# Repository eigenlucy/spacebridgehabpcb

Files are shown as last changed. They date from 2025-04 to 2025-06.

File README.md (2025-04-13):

# SpaceBridge HAB PCB

High Altitude Balloon (HAB) PCB Tracker with cutdown mechanism, GPS, environmental monitoring, LoRa telemetry and particle detection capabilities.

Created by Lucy Moglia <eigenlucy@proton.me>

## Table of Contents
- [Overview](#overview)
- [Project Structure](#project-structure)
- [Block Diagram](#block-diagram)
- [Features](#features)
- [Getting Started](#getting-started)
  - [Building the Project](#building-the-project)
  - [Installation](#installation)
    - [Linux Installation](#linux-installation)
    - [Mac Installation](#mac-installation)
    - [Visual Studio Code/Cursor Extension](#visual-studio-codecursor-extension-install)

## Overview

The SpaceBridge HAB PCB is a comprehensive tracking and instrumentation system for high altitude balloon experiments. It integrates multiple subsystems including power management, telemetry, GPS tracking, environmental monitoring, and a particle counter based on CERN open source hardware.

## Project Structure

| Module | Source File | PCB Layout | Description |
|:---:|:---:|:---:|:---|
| Mainboard | [`mainboard.ato`](./mainboard.ato) | [`layouts/default/default.kicad_pcb`](./layouts/default/default.kicad_pcb) | Final PCB incorporating all submodules |
| MicroMPPT | [`micromppt/elec/src/micromppt.ato`](./micromppt/elec/src/micromppt.ato) | [`micromppt/elec/layout/default/micromppt.kicad_pcb`](./micromppt/elec/layout/default/micromppt.kicad_pcb) | 5W MPPT battery charger with embedded set point adjustment algorithm |
| Particle Counter | [`particle_counter.ato`](./particle_counter.ato) | [`layouts/particle-counter/particle-counter.kicad_pcb`](./layouts/particle-counter/particle-counter.kicad_pcb) | Alpha particle detector based on CERN open source hardware kit |
| Cutoff Mechanism | [`cutoff.ato`](./cutoff.ato) | [`layouts/cutoff/cutoff.kicad_pcb`](./layouts/cutoff/cutoff.kicad_pcb) | Balloon cutoff circuit using lithium hybrid supercapacitor discharging through nichrome wire |
| BQ24045DSQR BMS | [`bq24045dsqr/elec/src/bq24045dsqr.ato`](./bq24045dsqr/elec/src/bq24045dsqr.ato) | [`bq24045dsqr/elec/layout/default/bq24045dsqr.kicad_pcb`](./bq24045dsqr/elec/layout/default/bq24045dsqr.kicad_pcb) | 5V 1A single cell LiPo/Li-ion charger + BMS |
| TPS63020DSJR | `~/.ato/modules/tps63020dsjr/elec/src/tps63020dsjr.ato` | `~/.ato/modules/tps63020dsjr/elec/layout/tps63020dsjr.kicad_pcb` | 1.8V-5.5V In/Out 4A boost-buck converter (5V from Vbat) |

## Block Diagram

### Original Block Diagram
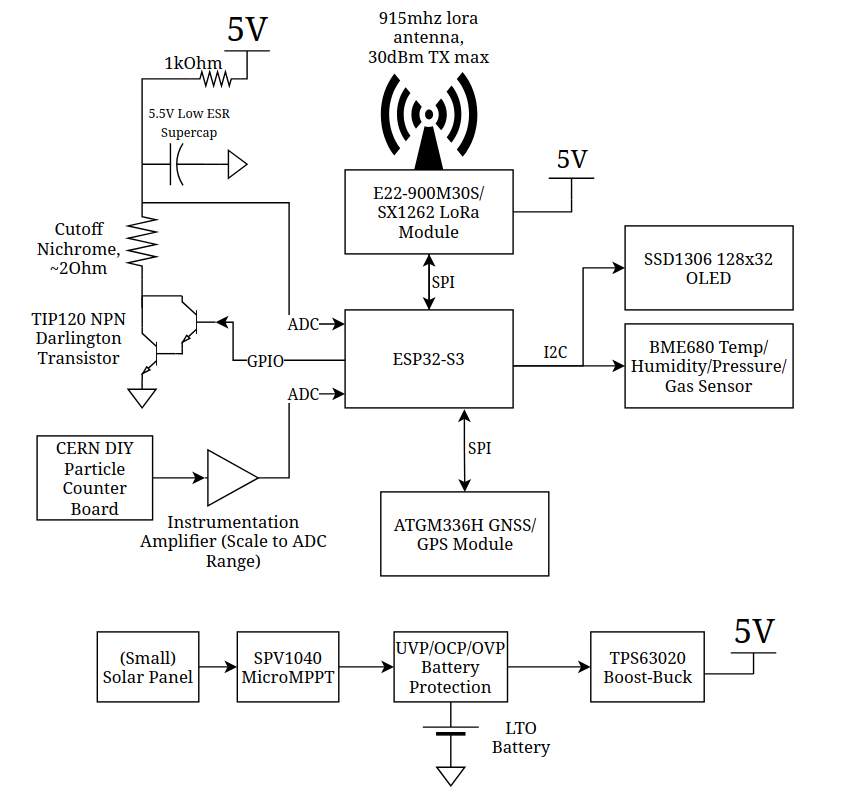
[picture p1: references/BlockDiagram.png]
Block Diagram


### Mermaid Diagram
```mermaid
graph TD
    %% Power System
    Solar["Solar Panel"] --> MPPT["SPV1040 MicroMPPT"]
    MPPT --> BattProt["UVP/OCP/OVP Battery Protection"]
    BattProt --- Battery["LTO Battery"]
    BattProt --> BoostBuck["TPS63020 Boost-Buck"]
    BoostBuck --> Power5V["5V Power Rail"]
    
    %% ESP32 Microcontroller (Central)
    ESP32["ESP32-S3"] 
    
    %% 5V Devices
    Power5V --> LoRa["E22-900M30S/SX1262 LoRa Module"]
    Power5V --> ParticleCounter["CERN DIY Particle Counter"]
    Power5V --> CutoffSystem["Cutoff System"]
    
    %% Cutoff System Components
    CutoffSystem --> Supercap["3.5V Low ESR Supercap"]
    CutoffSystem --> Nichrome["Nichrome Wire ~20Ω"]
    CutoffSystem --> TIP120["TIP120 NPN Darlington"]
    
    %% I2C Devices (3.3V)
    ESP32 -- I2C/IO6+IO7 --> OLED["SSD1306 128x32 OLED"]
    ESP32 -- I2C/IO6+IO7 --> BME680["BME680 Sensor"]
    ESP32 -- I2C/IO6+IO7 --> GPS["ATGM336H GNSS/GPS"]
    
    %% SPI Connections
    ESP32 -- SPI/IO10-13 --> LoRa
    
    %% GPIO Connections
    ESP32 -- GPIO0 --> Supercap["SC_GATE (Supercap Control)"]
    ESP32 -- GPIO1 --> TIP120["CUTOFF_GATE (Nichrome Control)"]
    
    %% ADC Connections
    ParticleCounter -- ADC/GPIO2 --> ESP32
    
    %% Antenna
    LoRa --- Antenna["915MHz LoRa Antenna (30dBm TX max)"]
    
    %% Styling
    classDef power fill:#f96,stroke:#333,stroke-width:2px
    classDef sensor fill:#bbf,stroke:#333,stroke-width:1px
    classDef communication fill:#f9f,stroke:#333,stroke-width:1px
    classDef controller fill:#9f6,stroke:#333,stroke-width:2px
    
    class Solar,MPPT,BattProt,Battery,BoostBuck,Power5V,Supercap power
    class BME680,ParticleCounter,GPS sensor
    class LoRa,Antenna,OLED communication
    class ESP32 controller
```

## Features

- **Power Management**: Solar charging with MPPT, battery protection and 5V regulation
- **Communication**: 915MHz LoRa radio for long-range telemetry (30dBm TX max)
- **Positioning**: ATGM336H GNSS/GPS module
- **Sensors**: 
  - BME680 temperature/humidity/pressure/gas sensor
  - CERN DIY particle counter for radiation detection
- **Display**: SSD1306 128x32 OLED screen
- **Control**: ESP32-S3 microcontroller
- **Recovery**: Nichrome wire cutdown mechanism for payload separation

## Getting Started

### Building the Project

1. **Clone the required submodules**
   ```
   git submodule update --init --recursive
   ```

2. **Build the project to select components based on JLCPCB availability**
   ```
   ato build -t all
   ```

3. **Complete/review the layout with KiCad Standalone PCB editor**

4. **Gerbers/PCBA files are generated through an Actions run on a commit**

### Installation

#### Linux Installation
1. Install [uv](https://github.com/astral-sh/uv)
2. Install KiCad with your preferred package manager (apt for Debian, pacman for Arch, etc.)
3. Install atopile as a tool with uv (Python 3.13.2 recommended):
   ```
   uv tool install atopile
   ```

   **Alternative installation method:**
   1. Clone the main [atopile repo](https://github.com/atopile/atopile)
   2. Remove the uv lock file:
      ```
      rm uv.lock
      ```
   3. Sync repo to dev release:
      ```
      uv sync --dev
      ```
   4. Compile atopile:
      ```
      uv build
      ```
   5. Install the binary:
      ```
      uv tool install atopile-0.3.XX-cp313-cp313-linux-_x86_64.whl
      ```
   6. Add the uv tools binary directory to your PATH (command depends on your shell, e.g., with fish):
      ```
      fish_add_path /home/user/.local/share/uv/tools/atopile/
      ```

4. Check your version:
   ```
   ato --version
   ```

5. Configure the atopile plugin:
   ```
   ato configure
   ```

#### Mac Installation
1. Install [Homebrew](https://brew.sh/)
2. Install [KiCad 9](https://formulae.brew.sh/cask/kicad):
   ```
   brew install --cask kicad
   ```
3. Install atopile with Homebrew:
   ```
   brew install atopile/tap/atopile
   ```
4. Configure the atopile plugin:
   ```
   ato configure
   ```

#### Visual Studio Code/Cursor Extension Install
Install the [atopile extension](https://marketplace.visualstudio.com/items?itemName=atopile.atopile) into Cursor or Visual Studio Code.

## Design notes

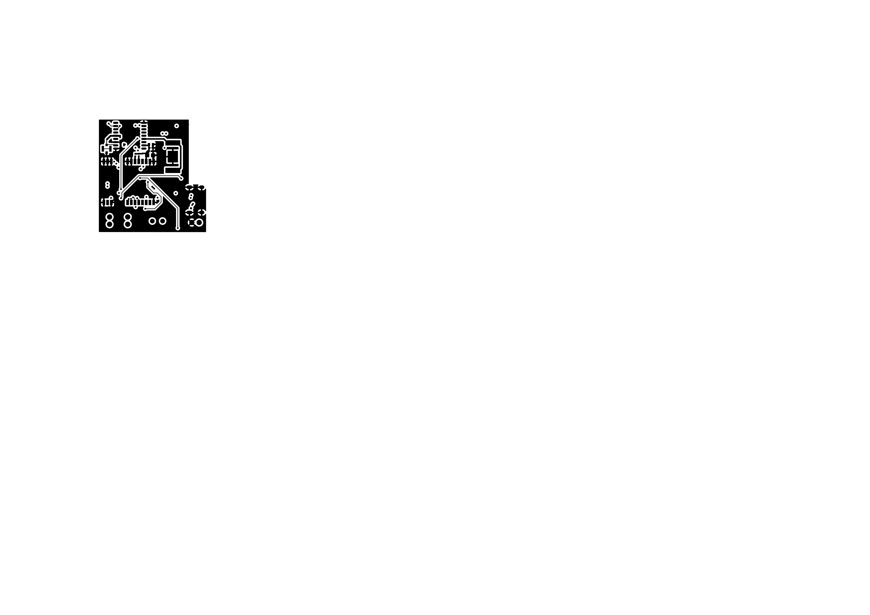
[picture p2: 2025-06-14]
3Dmodels/SVG/default-B_Cu.png

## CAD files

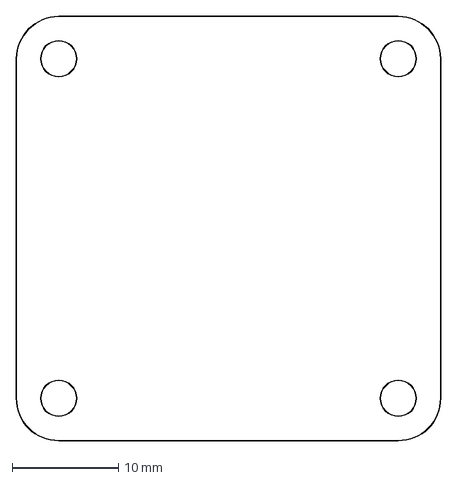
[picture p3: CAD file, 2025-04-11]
ams1117-33/mech/template_40x40.dxf
40.0 x 40.0 mm

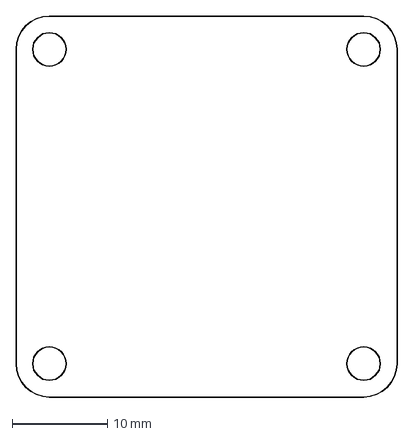
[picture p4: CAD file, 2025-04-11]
ams1117-33/mech/template_outline.dxf
40.0 x 40.0 mm

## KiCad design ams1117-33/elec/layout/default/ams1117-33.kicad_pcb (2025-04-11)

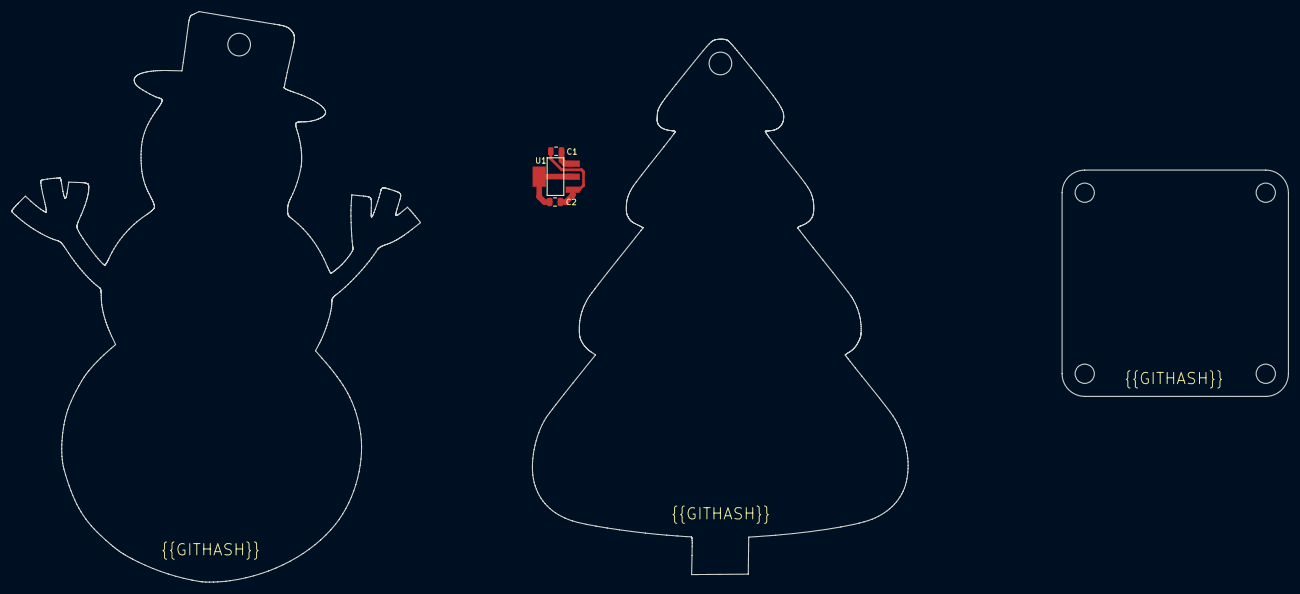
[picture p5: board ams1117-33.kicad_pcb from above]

Board: 2 copper layers, 66.4 x 94.6 mm, 3 parts (0 on the bottom side), 3 nets.

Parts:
C1, C2: 25V 10uF X5R ±10% 0805 Multilayer Ceramic Capacit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; C0805
U1: SOT-223-3_L6.5-W3.4-P2.30-LS7.0-BR

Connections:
gnd: C1.2, C2.2, U1.1
vcc: C1.1, U1.3
vcc-1: C2.1, U1.2, U1.4

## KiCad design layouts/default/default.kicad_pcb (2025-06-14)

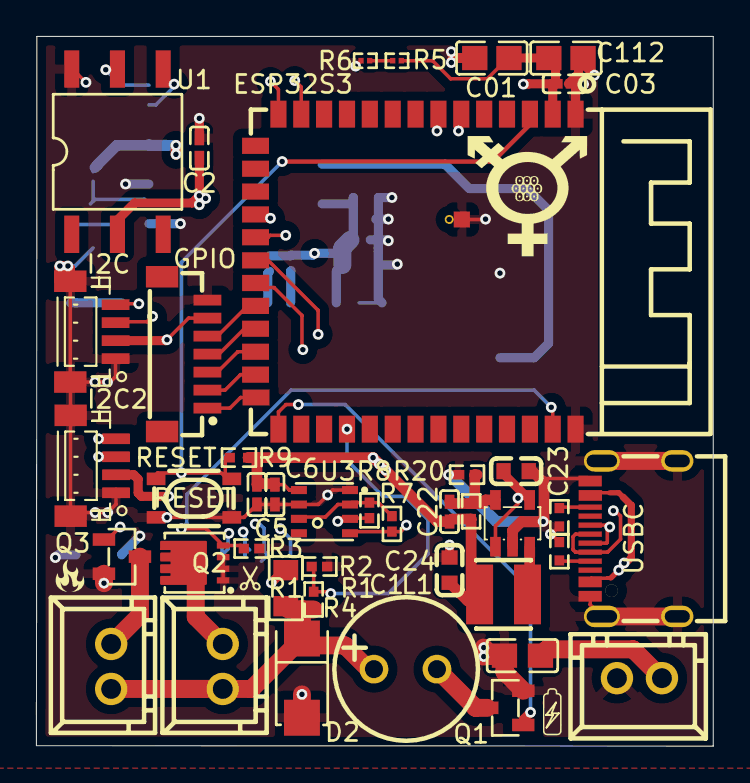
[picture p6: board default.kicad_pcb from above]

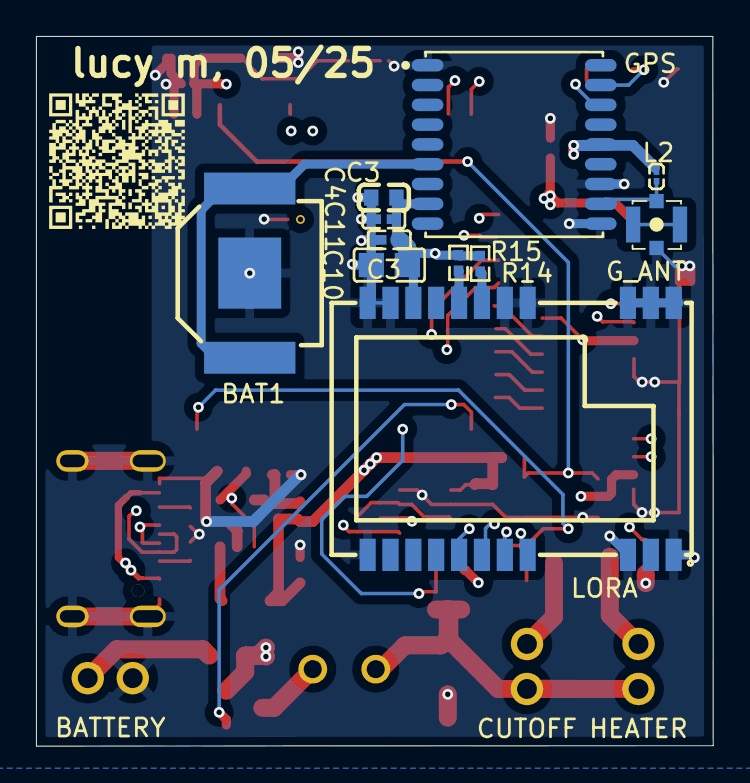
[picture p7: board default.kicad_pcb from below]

Board: 4 copper layers, 37.6 x 39.4 mm, 52 parts (11 on the bottom side), 36 nets.

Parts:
BAT1: BAT-SMD_C238096-012a28
BATTERY: CONN-TH_XH-2A-b4a6f6
C01, C112: 10µF ±10% 25V X5R; C0805-3b2e55
C1: CAP-TH_BD8.0-P3.50-D0.6-FD_1-b17e9d
C2, C03, C4, C5, C6, C11, C22: 100nF ±10% 16V X7R; C0402-b3ef17
C3, C23, C24: 100nF ±10% 50V X7R; C0603-bd72f6
C10, C30: 100nF ±10% 50V X7R; C0805-3b2e55
CUTOFF: CONN-TH_XH-2A-b4a6f6
D2: SMA_L4.3-W2.6-LS5.2-RD-e14692
ESP32S3: WIRELM-SMD_ESP32-S3-WROOM-1
GPIO: CONN-SMD_7P-P1.00_BM07B-SRSS-TB-201aba
GPS: GPSM-SMD_ATGM336H-TR-d79f58
G_ANT: IPEX-SMD_4P-L2.6-W2.6-LS3.0-f1620f
HEATER: CONN-TH_XH-2A-b4a6f6
I2C, I2C2: CONN-SMD_BM04B-SRSS-TB-6963ef
L1: IND-SMD_L3.0-W3.0-a13401
L2: L0201-8d2bbc
LORA: WIRELM-SMD_E22-900M22S-72e54e
Q1, Q3: SOT-23-3_L2.9-W1.3-P1.90-LS2.4-BR-688f29
Q2: DFN-8_L3.3-W3.3-P0.65-BL-2-bd6bc9
R1: 10kΩ ±1% 125mW; R0805-c79e8b
R2, R3, R4, R7, R8, R9, R14, R15: 10kΩ ±1% 62.5mW; R0402-56259e
R5: 10kΩ ±1% 50mW; R0201-27027e
R6: R0201-27027e
R20: 200kΩ ±1% 62.5mW; R0402-56259e
R21: 887kΩ ±1% 62.5mW; R0402-56259e
RESET: KEY-SMD_4P-L4.2-W3.2-P2.20-LS4.6
U1: SOP-6_L7.0-W7.0-P2.54-LS10.3-BL-0df1ed
U3: LGA-8_L3.0-W3.0-P0.80_BME688-7465bb
U19, U29: 5.1kΩ ±1% 62.5mW; R0402-56259e
U26: SOT-23-5_L3.0-W1.7-P0.95-LS2.8-BR-9d80aa
USBC: USB-C-SMD_KH-TYPE-C-16P

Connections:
A5: U19.1, USBC.A5
CC2: U29.1, USBC.B5
CSB: R7.2, R8.2, U3.2, U3.6
CUTOFF_GATE: ESP32S3.39, Q2.4, R3.1
FB: C22.2, R20.1, R21.2, U26.5
K: C1.1, CUTOFF.1, D2.1, HEATER.1, R1.2, R4.1
MISO: ESP32S3.21, LORA.16
MNT: G_ANT.1, G_ANT.3
MOSI: ESP32S3.19, LORA.17
NSS: ESP32S3.18, LORA.19
RF_IN: GPS.11, G_ANT.4, L2.2
RXEN: LORA.6, R14.2
Reserved: GPS.15, GPS.18
SCK: ESP32S3.20, LORA.18
SCL: ESP32S3.6, GPS.17, I2C.4, I2C2.4, R7.1, U1.5, U3.4
SC_GATE: ESP32S3.27, Q1.1
SC_Sense: ESP32S3.30, R2.1, R4.2
SDA: ESP32S3.7, GPS.16, I2C.3, I2C2.3, R8.1, U1.4, U3.3
SW: L1.1, U26.3
TEMP: R5.2, R6.1
TXEN: LORA.7, R15.2
VBAT: BAT1.1, BAT1.2, GPS.6
cutoff-C: CUTOFF.2, Q2.5
cutoff-C-1: HEATER.2, Q3.3
cutoff-C-2: C1.2, Q1.3
gnd: BAT1.3, BATTERY.2, C01.2, C2.2, C03.2, C3.2, C4.2, C5.2, C6.2, C10.2, C11.2, C23.2, C24.2, C30.2, C112.2, D2.2, ESP32S3.1, ESP32S3.40, ESP32S3.41, GPIO.7, GPS.1, GPS.10, GPS.12, G_ANT.2, I2C.0, I2C.1, I2C2.0, I2C2.1, LORA.1, LORA.2, LORA.3, LORA.4, LORA.5, LORA.10, LORA.11, LORA.12, LORA.20, LORA.22, Q1.2, Q2.1, Q2.2, Q2.3, Q3.2, R2.2, R3.2, R6.2, R20.2, RESET.3, RESET.4, U1.6, U3.1, U3.7, U19.2, U26.2, U29.2, USBC.1, USBC.2, USBC.3, USBC.4, USBC.A1, USBC.A12, USBC.B1, USBC.B12
hv: BATTERY.1, C23.1, C30.1, R1.1, U26.1, U26.4, USBC.A4, USBC.A9, USBC.B4, USBC.B9
hv-1: C01.1, C2.1, C03.1, C3.1, C4.1, C5.1, C6.1, C10.1, C11.1, C22.1, C24.1, C112.1, ESP32S3.2, GPIO.6, GPS.8, GPS.14, I2C.2, I2C2.2, L1.2, L2.1, LORA.9, R5.1, R9.1, R14.1, R15.1, R21.1, U1.2, U3.8
input: R9.2, RESET.1, RESET.2
io14: ESP32S3.22, GPIO.5
io19: ESP32S3.13, USBC.A7, USBC.B7
io20: ESP32S3.14, USBC.A6, USBC.B6
io21: ESP32S3.23, GPIO.4
io45: ESP32S3.26, GPIO.1
io47: ESP32S3.24, GPIO.3
io48: ESP32S3.25, GPIO.2

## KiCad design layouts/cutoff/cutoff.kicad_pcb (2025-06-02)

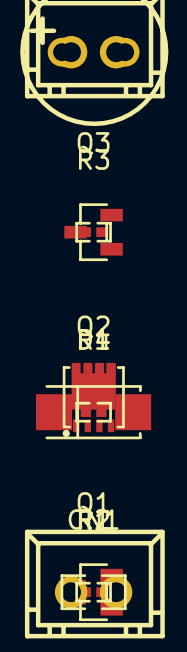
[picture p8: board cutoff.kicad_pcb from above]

Board: 2 copper layers, 11 parts (0 on the bottom side), 7 nets, no tracks yet.

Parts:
C1: CAP-TH_BD8.0-P3.50-D0.6-FD_1-b17e9d
CN1, CN2: CONN-TH_XH-2A-b4a6f6
D1: SMA_L4.3-W2.6-LS5.2-RD-e14692
Q1, Q3: SOT-23-3_L2.9-W1.3-P1.90-LS2.4-BR-688f29
Q2: DFN-8_L3.3-W3.3-P0.65-BL-2-bd6bc9
R1: 10kΩ ±1% 125mW; R0805-c79e8b
R2, R3, R4: 10kΩ ±1% 62.5mW; R0402-56259e

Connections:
C: C1.2, Q1.3
C-1: CN1.2, Q2.5
C-2: CN2.2, Q3.3
CUTOFF_GATE: Q2.4, R3.1
K: C1.1, CN1.1, CN2.1, D1.1, R1.2, R4.1
SC_Sense: R2.1, R4.2
gnd: D1.2, Q1.2, Q2.1, Q2.2, Q2.3, Q3.2, R2.2, R3.2

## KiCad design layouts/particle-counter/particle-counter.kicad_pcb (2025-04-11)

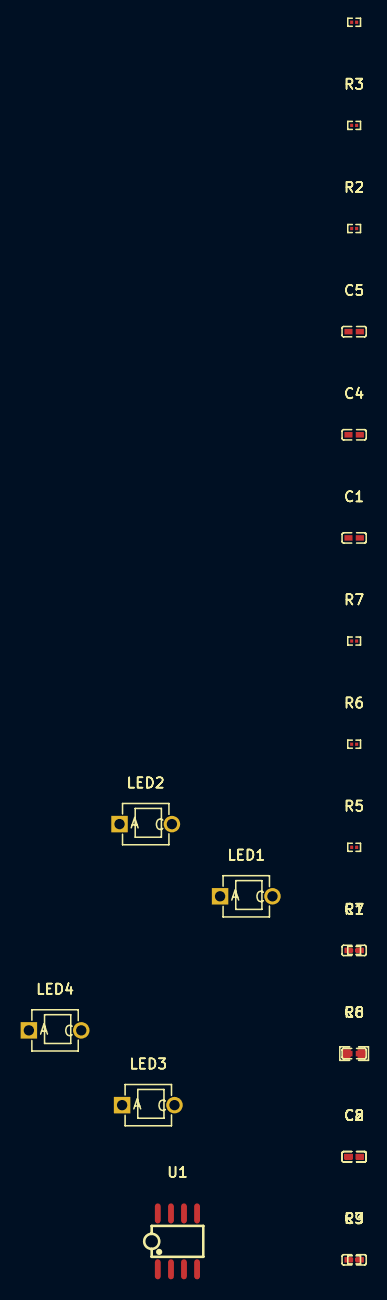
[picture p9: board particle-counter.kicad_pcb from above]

Board: 2 copper layers, 22 parts (0 on the bottom side), 11 nets, no tracks yet.

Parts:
C1, C2, C3, C4, C5, C6, C7, C8: 100nF ±10% 16V X7R; C0402-b3ef17
LED1, LED2, LED3, LED4: SENSOR-TH_BPW34-c0a4b0
R1, R2, R3, R4, R5, R6, R7, R9: 1kΩ ±1% 50mW; R0201-27027e
R8: 10kΩ ±1% 100mW; R0603-ebcab9
U1: SOIC-8_L5.0-W4.0-P1.27-LS6.0-BL-294f77

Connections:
IN1plus: R1.2, R2.1, U1.3
IN2minus: C5.1, R4.2, R5.1, U1.6
IN2plus: C6.1, R6.2, R7.1, U1.5
K: C1.1, LED1.2, LED2.2, LED3.2, LED4.2, R3.1, U1.2
OUT1: C1.2, C3.1, R3.2, U1.1
OUT2: C5.2, R5.2, R8.1, U1.7
VCC: C4.1, R1.1, R6.1, U1.8
gnd: C4.2, C6.2, C7.2, LED1.1, LED2.1, LED3.1, LED4.1, R2.2, R7.2, R9.2, U1.4
net: C7.1, C8.1, R8.2
net-1: C3.2, R4.1
out: C8.2, R9.1

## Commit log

2025-04-07 intial commit
    [default.kicad_pcb, micromppt.kicad_pcb]
2025-04-08 added sensors, darlington transistor
2025-04-08 finished particle counter connections
    [particle-counter.kicad_pcb]
2025-04-08 changed main target to mainboard, added cutoff build, lots of edits to modules
    [default.kicad_pcb, particle-counter.kicad_pcb]
2025-04-08 finished cutoff mechanism connections :fixed
    [cutoff.kicad_pcb, default.kicad_pcb, particle-counter.kicad_pcb]
2025-04-11 major updates
    [ams1117-33.kicad_pcb, ams1117-33.kicad_sch, bq24045dsqr.kicad_pcb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]
2025-04-11 added boost buck
    [cutoff.kicad_pcb, default.kicad_pcb, particle-counter.kicad_pcb]
2025-04-12 pcb layout
    [default.kicad_pcb, particle-counter.kicad_pcb]
2025-04-30 layout updates
    [cutoff.kicad_pcb, default.kicad_pcb]
2025-04-30 added new oled
    [cutoff.kicad_pcb, default.kicad_pcb]
2025-05-01 changed layout
    [cutoff.kicad_pcb, default.kicad_pcb]
2025-05-05 update before removing oled
    [cutoff.kicad_pcb, default.kicad_pcb]
2025-05-07 desktop push
    [cutoff.kicad_pcb, default.kicad_pcb]
2025-05-15 im cooking
    [cutoff.kicad_pcb, default.kicad_pcb]
2025-06-14 added ntc connection
    [default.kicad_pcb]
